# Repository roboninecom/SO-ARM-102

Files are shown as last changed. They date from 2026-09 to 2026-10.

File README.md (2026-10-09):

# SO-ARM 102

<div align="center">

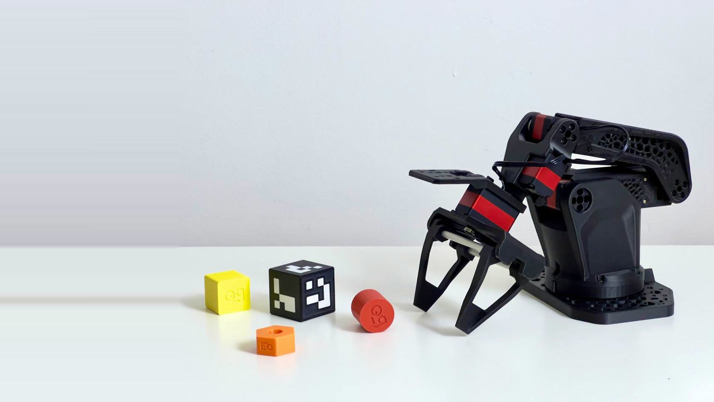
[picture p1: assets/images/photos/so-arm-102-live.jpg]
SO-ARM 102


**🎥 [Watch the preview video](assets/video/so-arm-102-preview.mp4)** · **🛒 [Buy the kit](https://robonine.com/shop/so-arm102-robotic-arm-kit/)**

**An open-source leader + follower robot arm kit with 5 degrees of freedom plus a gripper for teleoperation and imitation learning,
designed by [Robonine](https://robonine.com) as a stiffer, faster successor to the SO-ARM 101.**






📩 [hello@robonine.com](mailto:hello@robonine.com)

**DIY budget: ~$414 for components, or ~$469 including printing material.**
[BOM summary](#bill-of-materials) · [Itemised costs and purchase links](docs/bom.md#estimated-kit-cost)

> Rather not source the parts and print them yourself? **[Buy the SO-ARM 102 kit](https://robonine.com/shop/so-arm102-robotic-arm-kit/)**.

</div>

---

## ✨ What changed against SO-ARM 101

| | SO-ARM 101 | SO-ARM 102 |
|---|---|---|
| Gripper | Angular jaw | Parallel gripper, 85 mm span |
| Frame material | PLA | PET-CF (Fiberon PET-CF17 tested) |
| Structure | Solid links | Topology-optimised links |
| Base rotation range | 220° | **352°** |
| Horizontal reach | 441 mm | **483 mm** |
| Deflection at the gripper, 300 g load ¹ | 7.5 mm | **3.4–3.9 mm** |
| Shoulder and elbow speed | 45 RPM (STS3215) | **75 RPM (STS3250)** |
| Noise at 1 m | 70 dB | **60 dB** |

¹ Both arms built with printed servo dummies, so the frame is compared, not the motors.
Full results and test conditions are in [docs/specifications.md](docs/specifications.md).

The arm keeps the SO-ARM 101 joint layout, so it works with
[Hugging Face LeRobot](https://github.com/huggingface/lerobot) datasets and policies.

---

## 🎥 Preview

<div align="center">

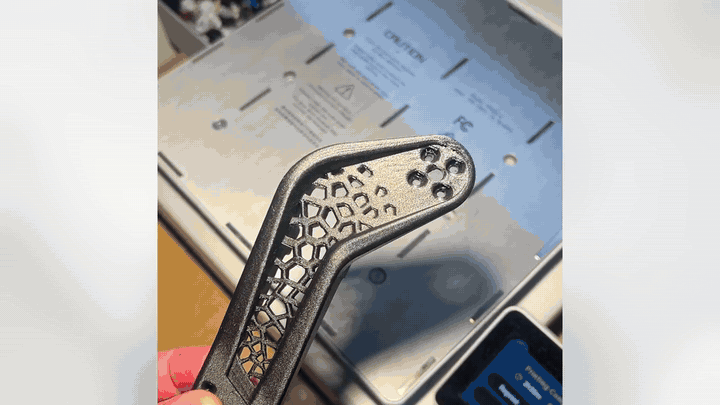
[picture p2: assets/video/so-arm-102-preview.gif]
SO-ARM 102 preview


*Click for the full video, 21 s*

</div>

---

## 🤝 Configurations

### Single-arm: one leader + one follower

The standard kit. Move the leader by hand, and the follower repeats the motion.
Use it for teleoperation and for recording demonstrations for imitation learning.

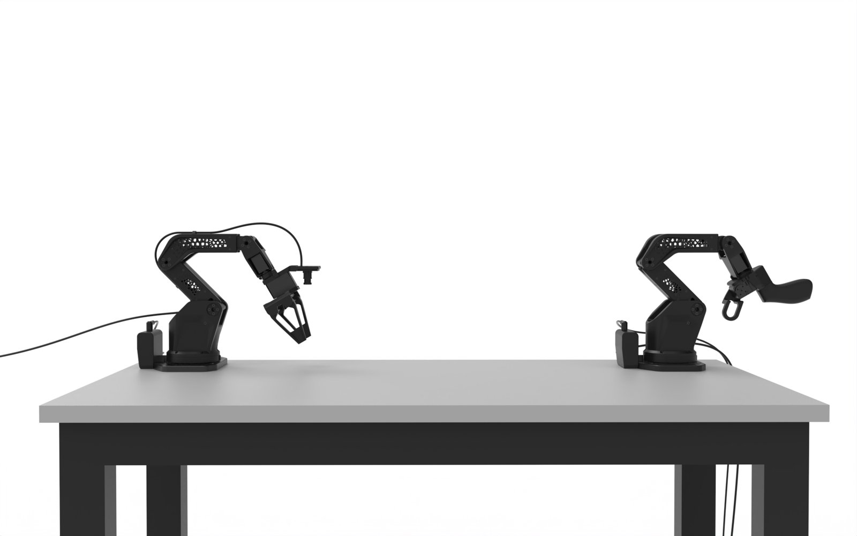
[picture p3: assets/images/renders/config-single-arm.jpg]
One leader and one follower


### Bimanual: two leaders + two followers

Two kits side by side. Each hand drives its own leader, so the followers can pass objects,
hold and work on a part, or do any task that needs two hands.

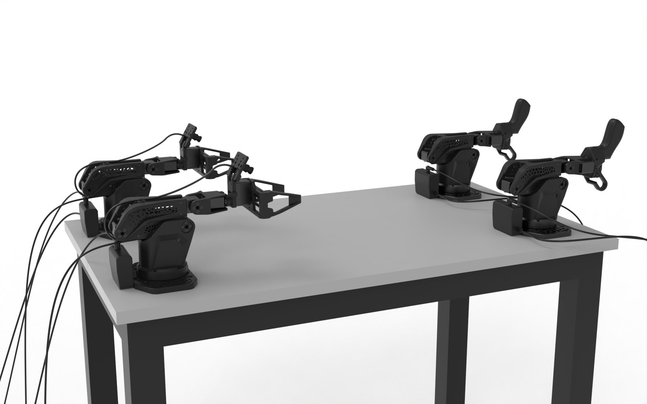
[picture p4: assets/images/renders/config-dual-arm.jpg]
Two leaders and two followers


### The two arms

| Follower | Leader |
|:-:|:-:|
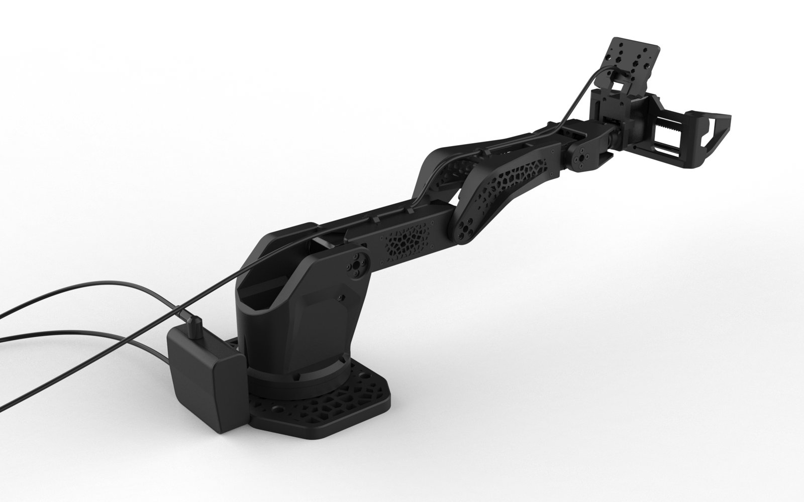
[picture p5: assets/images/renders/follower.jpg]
Follower arm
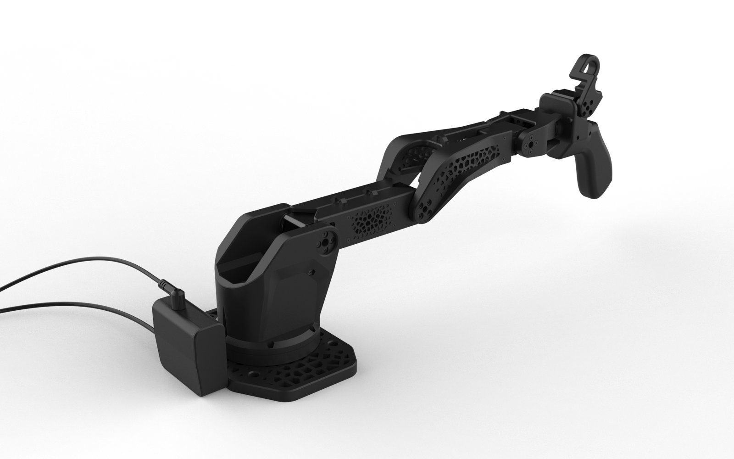
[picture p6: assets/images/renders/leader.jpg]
Leader arm
|  |  |
| Parallel gripper, wrist camera, 12 V | Handle with trigger, 5 V |

---

## 🚀 Build it in four steps

Prefer a ready kit? **[Buy the SO-ARM 102 kit](https://robonine.com/shop/so-arm102-robotic-arm-kit/)**.

### 1. Print the parts

Individual parts fit a 180 × 180 mm bed. The largest part is 160 mm long.
The supplied 3MF plate layouts use a 256 × 256 mm bed.

- 3MF slicer projects with saved orientation and support settings: [`models/3mf/`](models/3mf/)
  — [leader](models/3mf/SO102_leader.3mf), [follower arm](models/3mf/SO102_follower.3mf),
  [follower gripper and board case](models/3mf/SO102_follower_gripper_box.3mf)
- Project contents and printer profiles: [models/README.md](models/README.md)
- STL files, ready to slice: [`models/stl/`](models/stl/)
- STEP sources: [`models/step/`](models/step/)
- Material, settings and part quantities: [docs/printing.md](docs/printing.md)

The earlier test-arm settings gave slicer estimates of about 500 g of filament and 21 h
for the arm parts, excluding the gripper. Re-slice the 3MF projects for current estimates.

### 2. Buy the hardware

Source the components from the [BOM summary](#bill-of-materials) and
[full BOM with purchase links](docs/bom.md). Budget **$414.21** for components,
or **$469.19** including printing material, before shipping and taxes.

| Arm | Servos | Controller | Power |
|---|---|---|---|
| Follower | 2 × STS3235, 2 × STS3250, 2 × STS3215 | Waveshare Bus Servo Driver HAT | **12 V** |
| Leader | 6 × STS3215 | Waveshare Bus Servo Adapter | **5 V** |

> ⚠️ **The leader runs on 5 V and the follower on 12 V.** Do not swap the power supplies.

### 3. Assemble

- Printable booklet, 36 pages A5: [docs/SO-ARM102_assembly_A5_v0.6.pdf](docs/SO-ARM102_assembly_A5_v0.6.pdf)
- Step list with parts and fasteners: [docs/assembly-guide.md](docs/assembly-guide.md)

Tools: hex keys 1.5 mm (M2 screws) and 2 mm (M3 screws).

### 4. Set up the software

Servo IDs, calibration and lessons: **[lab.robonine.com](https://lab.robonine.com)**.
The arm uses the LeRobot SO-101 leader/follower workflow.

---

## Bill of materials

Quantities and reference costs for **one leader + one follower**:

| Category | Kit contents | Estimated cost (USD) |
|---|---|---:|
| Servos | 8 × STS3215, 2 × STS3235, 2 × STS3250 | $283.62 |
| Electronics | 2 controllers, 2 power supplies, 2 USB cables, 1 camera; servo cables included | $75.97 |
| Mechanical parts | 4 bearings, 2 steel guide rods, 4 table clamps | $40.76 |
| Fasteners | Screws and nuts; servo horn screws included with servos | $13.86 |
| **Components subtotal** | | **$414.21** |
| Printing material | 1 kg PET-CF17 + 0.25 kg PETG allowance | $54.98 |
| **Total with printing material** | | **$469.19** |

Buying the listed full packs and filament spools from scratch costs about **$545.17**,
including unused spares. Shipping, taxes, tools, a computer and a printer are excluded;
optional O-rings are extra. Confirm supplier prices, variants and minimum order quantities
before ordering. Re-slice the 3MF projects to check filament consumption.

[Full BOM, purchase links and cost assumptions](docs/bom.md#estimated-kit-cost).

---

## URDF export

The current standalone export is in [`simulation/urdf/`](simulation/urdf/):
[URDF](simulation/urdf/so_arm_102.urdf) · [Xacro](simulation/urdf/so_arm_102.xacro).
Keep `meshes/` beside the description files; mesh paths are relative to this folder.

- **Visuals:** STL meshes. **Collisions:** fitted, independently rotated boxes on all eight links.
- **Mass estimate:** PLA, 30% infill, 6 perimeters, 6 top/bottom layers,
  0.2 mm layer height, and **0.40 mm extrusion width**. These are simulation
  assumptions; use [the printing guide](docs/printing.md) for fabrication settings.
- **Hardware masses:** six motors at 70 g each; base bearing at 105 g.
  Total estimated model mass: **0.889 kg**.
- **Gripper:** `clamp2` mimics `clamp1` with multiplier `-1`.

[Export settings](simulation/urdf/export_settings.json) and
[mass properties](simulation/urdf/mass_properties.json) record the assumptions.
Geometry and inertia checks are recorded in

---

## 📁 Repository structure

```
├── models/
│   ├── 3mf/                 # Slicer projects: leader, follower, gripper and board case
│   ├── stl/                 # Print-ready meshes
│   │   ├── common/          #   parts used by both arms
│   │   ├── follower/        #   parallel gripper, camera mount, board case
│   │   └── leader/          #   handle, trigger, wrist roll, board case
│   └── step/                # CAD sources, same layout as stl/
├── docs/
│   ├── printing.md          # Material, slicer settings, quantities
│   ├── bom.md               # Bill of materials
│   ├── assembly-guide.md    # Step list with parts and fasteners
│   ├── specifications.md    # Geometry, servos, measured results vs SO-ARM 101
│   └── SO-ARM102_assembly_A5_v0.6.pdf
├── assets/
│   ├── images/              # Photos, renders, booklet pages, test photos
│   └── video/               # Preview video and GIF
├── LICENSING.md             # Which licence covers which file
└── NOTICE                   # Third-party attribution
```

---

## ⚠️ Known issues

This is the first public release. An independent test build found the following.
They are being fixed and will land in the next release.

1. **Two models are reported missing from the release set.** One is known: the camera holder still lacks a STEP source.
2. **M2 screws are hard to reach in several places.** Expect to fight a few of them.
3. **The gripper clamps run tight on carbon rods.** The clamp bores are sized for 6.1 mm. Rod diameters vary between suppliers, so check the fit before assembly.
4. **Check the servo cable lengths** before closing each joint, especially from the base to the shoulder.
5. **The assembly order is awkward in two places** of the booklet. Read two steps ahead before fastening.
6. **Leader joints can feel loose.** Adding 8 × 2 mm rubber O-rings between each servo and its horn gives the leader smooth, silent friction. Use two per servo on joints 1–4 and one on joints 5–6.

Found something else? Please [open an issue](https://github.com/roboninecom/SO-ARM-102/issues).

---

## 🔗 Related projects

- [SO-ARM100/101 Parallel Gripper](https://github.com/roboninecom/SO-ARM100-101-Parallel-Gripper), the gripper the SO-ARM 102 gripper grew from
- [SO-ARM101](https://github.com/TheRobotStudio/SO-ARM100) by TheRobotStudio, the arm this design succeeds
- [Practical comparison of smart serial servos](https://robonine.com/smart-serial-servo-motor-comparison-robotics/), the tests behind the servo choice
- [Choosing a filament for robotic arms](https://robonine.com/choosing-filament-for-robotic-arm-applications/), the tests behind PET-CF

---

## 📄 License

Copyright (c) 2026 Robonine. Different kinds of material carry different licences:

| Material | Licence |
|---|---|
| Hardware designs in `models/` | [CERN-OHL-P-2.0](HARDWARE-LICENSE.txt) |
| Software and configuration | [Apache-2.0](SOFTWARE-LICENSE.txt) |
| Documentation and images in `docs/`, `assets/`, all `README.md` | [CC BY 4.0](DOCS-LICENSE.txt) |

See [LICENSING.md](LICENSING.md) and [REUSE.toml](REUSE.toml) for the file-by-file map.

---

## 👥 Team

| Name | Role | Contact |
|---|---|---|
| **Alan Subin** | Design Engineer: mechanical design, CAD, assembly booklet | [LinkedIn](https://www.linkedin.com/in/alan-subin/) |
| **Boris Kotov** | Software and Test Engineer: prototypes, printing, test rigs | [Telegram](https://t.me/bkotov) |
| **Nikita Bragin** | Project Manager | [LinkedIn](https://www.linkedin.com/in/nikita-bragin-82296b29/) |
| **Mikhail Chistiakov** | Industrial Designer: look and form of the arm | [Telegram](https://t.me/brrryska) |
| **Mikhail Zhmaylo** | Structural Engineer: stiffness models, design changes to cut deflection | [Telegram](https://t.me/mikhail_zhmaylo) |
| **Vladislav Eremenko** | Structural Engineer: strength and thermal analysis, topology optimisation | [Telegram](https://t.me/v1ad_eremenko) |
| **Vladimir Osipov** | Tester and Consultant: independent test build | [LinkedIn](https://www.linkedin.com/in/vladimirosipov/) |

<div align="center">

**Built for the robotics community by [Robonine](https://robonine.com)** 🤖

</div>

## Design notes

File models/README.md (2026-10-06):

# 3D models

| Folder | Content |
|---|---|
| `3mf/` | Bambu Studio projects with saved plate layouts, orientation and support settings |
| `stl/` | Print-ready meshes, binary STL, millimetres |
| `step/` | CAD sources, one solid per file |

The `stl/` and `step/` folders use the same split:

- `common/` holds the parts both arms use. The quantities in the print table cover the whole kit.
- `follower/` holds the parallel gripper, the camera mount and the follower board case.
- `leader/` holds the handle, trigger, wrist roll and the leader board case.

## 3MF slicer projects

| Project | Contents | Saved filament profile |
|---|---|---|
| [SO102_leader.3mf](3mf/SO102_leader.3mf) | One leader: arm parts, handle, trigger, wrist roll and board case | Bambu PETG-CF |
| [SO102_follower.3mf](3mf/SO102_follower.3mf) | One follower's arm parts | Fiberon PET-CF17 |
| [SO102_follower_gripper_box.3mf](3mf/SO102_follower_gripper_box.3mf) | Follower gripper, camera holder and spacer, and board case | Bambu PETG-CF |

Open these files as projects in **Bambu Studio** to retain the saved settings.
All three use the **Bambu Lab A1, 0.4 mm nozzle** profile and one **256 × 256 mm** plate each.
Select your printer, nozzle and filament before slicing. For a smaller bed, split the parts
across additional plates while preserving their orientations and support settings.

For one leader + one follower, print all three projects once. The arm projects each include
the common parts for one arm; there is no need to print a separate common set.

Saved settings and layout previews are in [docs/printing.md](../docs/printing.md#3mf-slicer-projects).

Part numbers, quantities and print settings are in [docs/printing.md](../docs/printing.md).

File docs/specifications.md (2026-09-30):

# Specifications and test results

Measured on Robonine prototypes in August and September 2026.
Numbers marked *calculated* come from the URDF model and servo datasheets, not from a measurement.

## Geometry

| Joint | Range |
|---|---|
| Base rotation | −176° … +176° (352°) |
| Shoulder lift | −43° … +181° (224°) |
| Elbow flex | −166° … +77° (243°) |
| Wrist flex | −85° … +111° (196°) |
| Wrist roll | −165° … +163° (328°) |
| Gripper | 0 … 85 mm |

| Link | Axis to axis |
|---|---|
| Base rotation to shoulder | 85 mm |
| Shoulder to elbow | 119 mm |
| Elbow to wrist flex | 139 mm |
| Wrist flex to wrist roll | 62 mm |
| Wrist roll to gripper tip | 132 mm |

| Reach, gripper tip centre | |
|---|---|
| Horizontal radius | 483 mm |
| Height above the base bottom | up to 544 mm |
| Below the base bottom, arm over a table edge | down to −301 mm |

Reach was computed from 100,000 random poses within the joint limits, with no self-collisions.

## Servos

| Joint | Follower | Leader |
|---|---|---|
| 1 Base rotation | STS3235 | STS3215 |
| 2 Shoulder lift | STS3250 | STS3215 |
| 3 Elbow flex | STS3250 | STS3215 |
| 4 Wrist flex | STS3235 | STS3215 |
| 5 Wrist roll | STS3215 1:345 | STS3215 |
| 6 Gripper / trigger | STS3215 | STS3215 |
| Supply | 12 V | 5 V |

## Gripper

| | |
|---|---|
| Type | Parallel, rack and pinion, two moving jaws |
| Span | 85 mm |
| Box, recommended maximum width | about 75 mm |
| Cylinder, recommended maximum diameter | about 70 mm |
| Sphere, recommended maximum diameter | about 60 mm |
| Camera | USB camera mounted on the gripper |

## Measured results against SO-ARM 101

| Metric | SO-ARM 101 | SO-ARM 102 | Change |
|---|---|---|---|
| Deflection at the gripper tip, 300 g, arm fully extended ¹ | 7.5 mm | 3.4 mm | −55 % |
| Same, all links at 100 % infill ¹ | — | 2.34 mm | −69 % |
| Horizontal radius | 441 mm | 483 mm | +9.5 % |
| Reach behind the base | 377 mm | 473 mm | +25.5 % |
| Base rotation range | 220° | 352° | +60 % |
| Elbow range | 194° | 243° | +25 % |
| Shoulder and elbow no-load speed, *calculated* | 270 °/s | 450 °/s | +67 % |
| Base joint backlash | 8.75 counts | 5.00 counts | −43 % |
| Horizontal tip error from base backlash, *calculated* | ±2.96 mm | ±1.85 mm | −37.5 % |
| Repeatability | — | about 0.1 mm | |
| Noise at 1 m | 70 dB | 60 dB | −10 dB |
| Rated payload | 250 g | 300 g | |

¹ Both arms were built with printed servo dummies in joints 2, 3 and 4, so only the frame is compared.
SO-ARM 101 printed in PLA, SO-ARM 102 in Fiberon PET-CF17 at 25 % infill.
A second run of the same SO-ARM 102 test gave 3.9 mm.

| SO-ARM 101 | SO-ARM 102 |
|:-:|:-:|
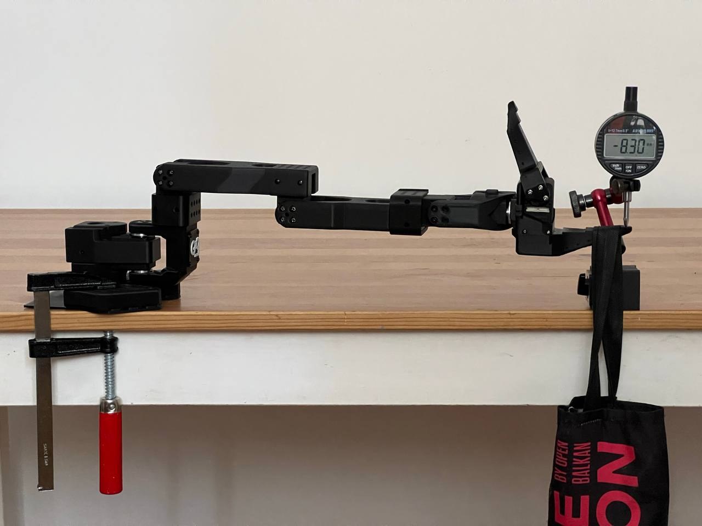
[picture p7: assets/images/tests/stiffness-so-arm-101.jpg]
SO-ARM 101 stiffness test
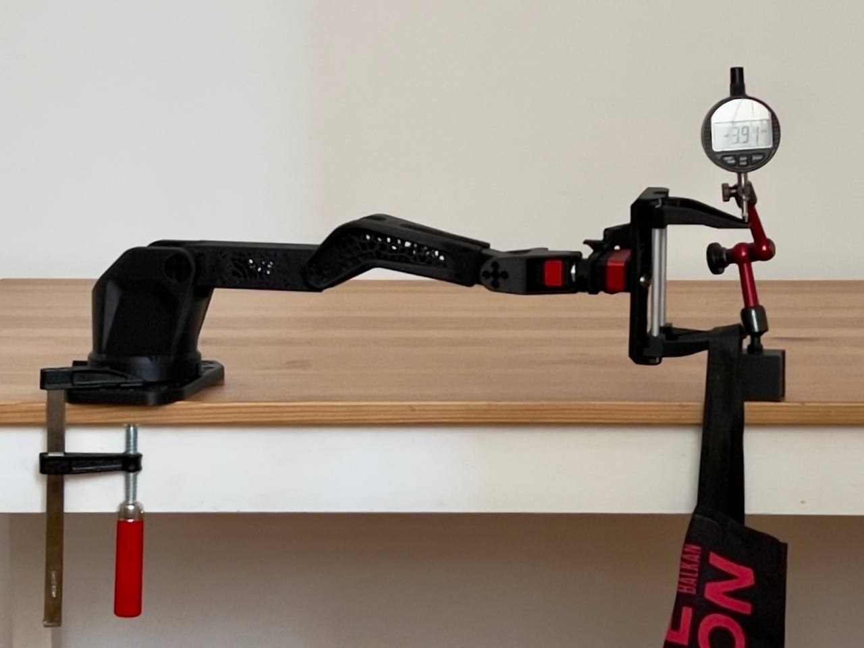
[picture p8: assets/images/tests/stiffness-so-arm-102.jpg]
SO-ARM 102 stiffness test
|  |  |

## Current and temperature, follower

Measured with a 300 g load on a repeating trajectory, ambient 30 °C, six STS3250 servos.

| | |
|---|---|
| Current, average | 1.26 A |
| Current, peak | 3.28 A |
| Servo temperature, maximum | 46 °C |

## Absolute accuracy

Still being tuned. With stock servo PID settings the tip sagged about 50 mm under the arm's own weight at full extension.
Tuned PID settings brought that down to about 5 mm. A dedicated accuracy profile is in progress.

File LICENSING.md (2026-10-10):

# Licensing

Copyright (c) 2026 Robonine

This project releases different kinds of material under different licences.
Every file in this repository is covered by exactly one of them.

| Material | Licence | Text |
|---|---|---|
| Hardware designs (CAD, manufacturable geometry) | CERN-OHL-P-2.0 | [`HARDWARE-LICENSE.txt`](HARDWARE-LICENSE.txt) |
| Software (configuration, CI) | Apache-2.0 | [`SOFTWARE-LICENSE.txt`](SOFTWARE-LICENSE.txt) |
| Documentation, renders, photographs and simulation assets | CC-BY-4.0 | [`DOCS-LICENSE.txt`](DOCS-LICENSE.txt) |

The machine-readable version of this map is [`REUSE.toml`](REUSE.toml).
`LICENSES/` holds the same three texts under their SPDX names, as the REUSE Specification requires.
The copies at the root are the ones GitHub's licence detection reads.

## 1. Hardware: CERN-OHL-P-2.0

```
models/step/    *.STEP
models/stl/     *.stl
models/3mf/     *.3mf (geometry and slicer projects)
```

`models/README.md` is documentation and falls under CC-BY-4.0.

Recommended notice when reusing this hardware:

```
Copyright (c) 2026 Robonine

This source describes Open Hardware and is licensed under the CERN-OHL-P v2.
You may redistribute and modify this source and make products using it under
the terms of the CERN-OHL-P v2 (https://ohwr.org/cern_ohl_p_v2.txt).

This source is distributed WITHOUT ANY EXPRESS OR IMPLIED WARRANTY, INCLUDING
OF MERCHANTABILITY, SATISFACTORY QUALITY AND FITNESS FOR A PARTICULAR PURPOSE.

SPDX-License-Identifier: CERN-OHL-P-2.0
```

## 2. Software: Apache-2.0

```
.github/    .pre-commit-config.yaml    .gitignore    .gitattributes
```

## 3. Documentation and simulation assets: CC-BY-4.0

```
README.md, CONTRIBUTING.md, LICENSING.md, CLAUDE.md, NOTICE
docs/             *.md, *.pdf
assets/images/    *.jpg
assets/video/     *.mp4, *.gif
simulation/       all files, including URDF/Xacro descriptions, meshes and export metadata
every other README.md in the repository
```

All files under `simulation/` are licensed under CC-BY-4.0. This includes the
robot descriptions in `simulation/urdf/` and their referenced STL meshes in
`simulation/urdf/meshes/`. The fabrication designs under `models/` remain
licensed under CERN-OHL-P-2.0 as described above.

Attribution for reuse: "Robonine, SO-ARM 102, https://github.com/roboninecom/SO-ARM-102, CC BY 4.0".

## 4. Third-party material

No file in this repository is copied from a third party.
See [`NOTICE`](NOTICE) for the projects this design builds on.

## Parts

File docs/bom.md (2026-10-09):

# Bill of materials

Quantities are for one complete kit: one follower arm and one leader arm.
Printed parts are listed separately in [printing.md](printing.md).

## Estimated kit cost

**One leader + one follower: $414.21 in components, or $469.19 including printing material.**

| Category | Cost of quantities used (USD) | Buy full packs / spools (USD) |
|---|---:|---:|
| Servos (12) | $283.62 | $283.62 |
| Electronics, camera, power supplies and USB cables | $75.97 | $75.97 |
| Bearings, steel guide rods and table clamps | $40.76 | $55.88 |
| Fasteners (servo horn screws included with servos) | $13.86 | $59.72 |
| **Components subtotal** | **$414.21** | **$475.19** |
| Printing material: 1 kg PET-CF17 + 0.25 kg PETG | $54.98 | $69.98 |
| **Total with printing material** | **$469.19** | **$545.17** |

Estimates use the reference prices listed below, with each line rounded to cents.
They are not new supplier quotes: confirm the selected variants, minimum order
quantities and prices before ordering. Shipping, taxes, tools, a computer, a printer,
electricity and assembly labour are excluded. Optional O-rings add $0.72 in parts
used, or $6.00 for a pack of 100; tools add about $10.00 if needed.

The full-pack column includes unused spares, two 0.5 kg PET-CF17 spools and one
1 kg PETG spool. Printing quantities are budget allowances; re-slice the supplied
3MF projects for your settings. Rod costs use steel; carbon tubes are an alternative.

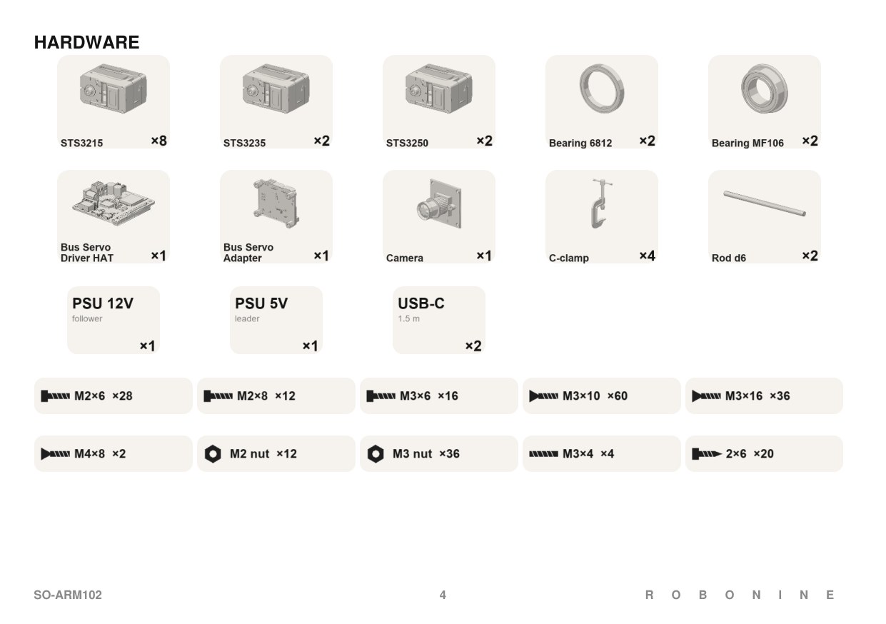
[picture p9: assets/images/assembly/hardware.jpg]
Kit hardware


## Servos

| Joint | ID | Follower | Leader |
|---|:-:|---|---|
| Base rotation | 1 | ST-3235-С001 | ST-3215-C044, 1:191 |
| Shoulder lift | 2 | ST-3250-С002 | ST-3215-C044, 1:191 |
| Elbow flex | 3 | ST-3250-С002 | ST-3215-C044, 1:191 |
| Wrist flex | 4 | ST-3235-С001 | ST-3215-C044, 1:191 |
| Wrist roll | 5 | ST-3215-C049, 1:191 | ST-3215-C044, 1:191 |
| Gripper / Trigger | 6 | ST-3215-C049, 1:191 | ST-3215-C044, 1:191 |

Totals: 6 × STS3215 7.4V, 2 × STS3215 12V, 2 × STS3235 12V, 2 × STS3250 12V. All are Feetech TTL serial bus servos.

| Servo | Qty | Purchase link | Selection | Unit price (USD) | Kit cost (USD) |
|---|---|---|---|---|---|
| STS3215 | 6 | [Alibaba](https://www.alibaba.com/product-detail/Top-Seller-Low-Cost-Feetech-STS3215_1600999461525.html) | 7.4V TTL version for leader servos. Select ST-3215-C044 (7.4V). | $13.89 | $83.34 |
| STS3215 | 2 | [Alibaba](https://www.alibaba.com/product-detail/6pcs-12V-30KG-1-345-STS3215_1601900233170.html) | 12V TTL version for follower joints 5 and 6. Select ST-3215-C049 (12V30KG). | $14.70 | $29.40 |
| STS3235 | 2 | [Alibaba](https://www.alibaba.com/product-detail/FEETECH-STS3235-12V-30KG-TTL-Dual_1601910640629.html) | 12V TTL version for follower joints 1 and 4. | $40.79 | $81.58 |
| STS3250 | 2 | [Alibaba](https://www.alibaba.com/product-detail/Feetech-STS3250-12V-50kg-Servo-High_1601711893549.html) | 12V TTL version for follower joints 2 and 3. | $44.65 | $89.30 |

- **Follower, 12V.** STS3250 is a 50 kg·cm brushless servo at 75 RPM. It drives the two joints that carry the most load.
  STS3235 is a 30 kg·cm servo with lower backlash than the STS3215.
- **Leader, 5V.** The leader servos are only read, never loaded. You can use a passive STS3215 (ST-3215-C066) without motor and gearbox **only** for leader arm.
- Servo horns and the M3 × 6 horn screws come with the servos.

## Electronics

| Item | Qty | Notes | Purchase link | Unit / pack price (USD) | Kit cost (USD) |
|---|---|---|---|---|---|
| Waveshare Bus Servo Driver HAT | 1 | Follower controller | [Waveshare HAT (A)](https://www.waveshare.com/product/robotics/bus-servo-driver-hat-a.htm) | $18.99 | $18.99 |
| Waveshare Bus Servo Adapter | 1 | Leader controller | [Waveshare Adapter (A)](https://www.waveshare.com/bus-servo-adapter-a.htm) | $4.99 | $4.99 |
| Power supply 12V DC | 1 | Follower. 60W / 5A or more recommended. The arm peaked at 3.3A under a 300g load. Match the HAT's connector (5.5x2.5mm). | [Amazon search](https://www.amazon.com/s?k=12V+5A+power+supply+5.5+2.5mm) | ~$20.00 | $20.00 |
| Power supply 5V DC | 1 | Leader. Match the Adapter's connector (5.5x2.1mm). | [Amazon search](https://www.amazon.com/s?k=5V+power+supply+5.5+2.1mm) | ~$10.00 | $10.00 |
| USB-C cable, 1.5 m | 2 | One per controller. Choose a data cable, not a charging-only cable. | [Amazon search](https://www.amazon.com/s?k=USB+A+to+USB+C+data+cable+1.5m) | ~$7.00 / 2 | $7.00 |
| USB camera, 1080p | 1 | Wrist camera on the follower gripper. The prototype used an OV2735 module. Check module dimensions and mounting holes against the camera holder. | [Waveshare OV2735](https://www.waveshare.com/ov2735-2mp-usb-camera-a.htm) | $14.99 | $14.99 |
| Servo cables | 12 | Come with the servos. Pay attention during assembly where to put 4 long cables from STS3250 packing. | Included with the [servos](#servos); [Amazon search for spares](https://www.amazon.com/s?k=Feetech+STS3215+TTL+servo+cable) | Included | $0.00 |

## Mechanical parts

| Item | Size | Qty | Where | Purchase link | Unit / pack price (USD) | Kit cost (USD) |
|---|---|---|---|---|---|---|
| Ball bearing 6812 | 60 × 78 × 10 mm | 2 | Base rotation, one per arm | [Amazon search](https://www.amazon.com/s?k=6812+bearing+60+78+10mm) | ~$7.00 | $14.00 |
| Flanged bearing MF106ZZ | 6 × 10 × 3 mm | 2 | Gripper main frame | [Amazon](https://www.amazon.com/uxcell-MF106ZZ-6x10x3mm-Shielded-Bearings/dp/B08H289LLQ) | $9.99 / 10 | $2.00 |
| Rod | Ø6 × 125 mm, carbon or steel | 2 | Gripper guides | [Amazon steel rods](https://www.amazon.com/SKYPRO-Stainless-Diameter-Industry-Working/dp/B0CLCSWSJ9) · [Amazon carbon tubes](https://www.amazon.com/MECCANIXITY-Carbon-Pultruded-Airplane-Quadcopter/dp/B0CZDCW2NL) (cut to 125 mm) | $11.89 / 5 steel rods | $4.76 |
| C-clamp | 3 inch, 0–75 mm opening | 4 | Two per arm, to fix the base to the table | [Amazon search](https://www.amazon.com/s?k=3+inch+C+clamp+75mm) | ~$5.00 | $20.00 |
| Rubber O-ring, optional | 8 × 2 mm | 12 | Adds friction to the leader joints. Two per servo on joints 1–4, one on joints 5–6. | [Amazon search](https://www.amazon.com/s?k=rubber+O+ring+8mm+inner+diameter+2mm+cross+section) | ~$6.00 / 100 | $0.72 (optional) |

## Fasteners

Kit totals as packed in the assembly booklet.

| Fastener | Standard | Qty | Purchase link | Unit / pack price (USD) | Kit cost (USD) |
|---|---|---|---|---|---|
| M2 × 6 socket head | DIN 912 | 28 | [Amazon search](https://www.amazon.com/s?k=DIN+912+M2x6+socket+head+screw) | ~$6.99 / 100 | $1.96 |
| M2 × 8 socket head | DIN 912 | 12 | [Amazon](https://www.amazon.com/TOP-VIGOR-Stainless-Replacement-Motorcycle-Repairment/dp/B0D5CHC6GR) | $6.79 / 120 | $0.68 |
| M3 × 6 Phillips-head screw | from servo kit | 16 | Included with the [servos](#servos). | Included | $0.00 |
| M3 × 10 countersunk | DIN 7991 | 60 | [Amazon search](https://www.amazon.com/s?k=DIN+7991+M3x10+countersunk+screw) | ~$6.99 / 100 | $4.20 |
| M3 × 16 countersunk | DIN 7991 | 36 | [Amazon search](https://www.amazon.com/s?k=DIN+7991+M3x16+countersunk+screw) | ~$6.99 / 100 | $2.52 |
| M4 × 8 countersunk | DIN 7991 | 2 | [Amazon](https://www.amazon.com/Socket-Countersunk-Stainless-Screwdriver-Included/dp/B0DWZVYSMZ) | $6.99 / 100 | $0.14 |
| M3 × 4 set screw | DIN 913 | 4 | [Amazon](https://www.amazon.com/Socket-M3-0-5-Metric-14-9-45H-Quantity/dp/B07CPNB1WP) | $6.99 / 100 | $0.28 |
| M2 hex nut | DIN 934 | 12 | [Amazon](https://www.amazon.com/QXSKSLH-Metric-Stainless-Hex-Nuts-100pcs/dp/B0CSWRN19Q) | $5.99 / 100 | $0.72 |
| M3 hex nut | DIN 934 | 36 | [Amazon search](https://www.amazon.com/s?k=DIN+934+M3+hex+nut) | ~$5.99 / 100 | $2.16 |
| Self-tapping screw 2 × 6 | — | 20 | [Amazon search](https://www.amazon.com/s?k=2mm+x+6mm+self+tapping+screw) | ~$6.00 / 100 | $1.20 |

Black fasteners match the look of the renders but are not required.

## Printing materials

| Material | Use | Purchase link | Price / budget (USD) |
|---|---|---|---|
| Fiberon PET-CF17 | Tested material for the arm links, bases and servo holders | [Polymaker](https://shop.polymaker.com/products/fiberon-pet-cf17) | $24.99 / 0.5 kg; budget 2 spools = $49.98 |
| PETG or PET-CF | Gripper clamps, covers, leader handle and trigger | [Amazon PETG search](https://www.amazon.com/s?k=PETG+filament+1.75mm) · [Polymaker PET-CF17](https://shop.polymaker.com/products/fiberon-pet-cf17) | PETG: ~$20.00 / kg; 0.25 kg allowance = $5.00 |

Use the [printing guide](printing.md) and re-slice the supplied 3MF projects to determine
the filament quantity for your printer and settings.

## Tools

Allow about **$10.00** for a small hex-key and screwdriver set if you do not already own these tools.

- Hex key 1.5 mm for M2 screws: [Amazon search](https://www.amazon.com/s?k=1.5mm+hex+key)
- Hex key 2 mm for M3 screws: [Amazon search](https://www.amazon.com/s?k=2mm+hex+key)
- Phillips PH1 screwdriver for servo horn screws: [Amazon search](https://www.amazon.com/s?k=PH1+Phillips+screwdriver)

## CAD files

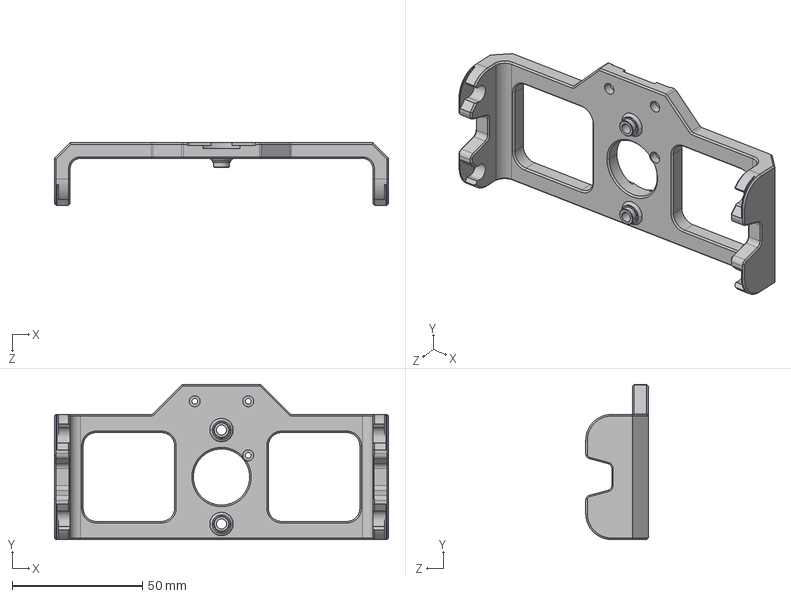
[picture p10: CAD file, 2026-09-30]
models/step/follower/RB9.01.062.011 Main frame (D6.1).STEP
128.0 x 59.5 x 24.0 mm

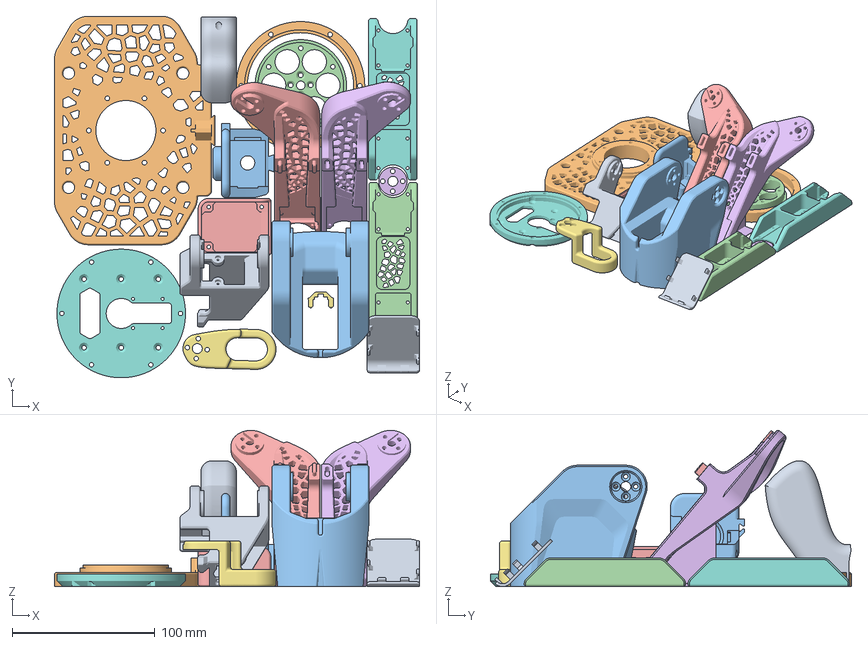
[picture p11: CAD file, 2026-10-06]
models/3mf/SO102_leader.3mf
255.6 x 253.1 x 109.4 mm
Handle_SO102
SO102.01.010 Base
Wrist_Roll_SO102
SO102.02.020 Base ring
SO102.02.110 Board holder leader
SO102.02.030 Base washer
Trigger_SO102
SO102.02.040 Bottom top plate
SO102.02.110-01 Board cap leader
SO102.02.050 Bottom ring
SO102.02.060 Bottom servo holder
SO102.02.070 Bottom arm x 2
SO102.02.080 Upper arm left
SO102.02.080-01 Upper arm right
SO102.02.130 Cable snap
SO102.02.090 Wrist holder

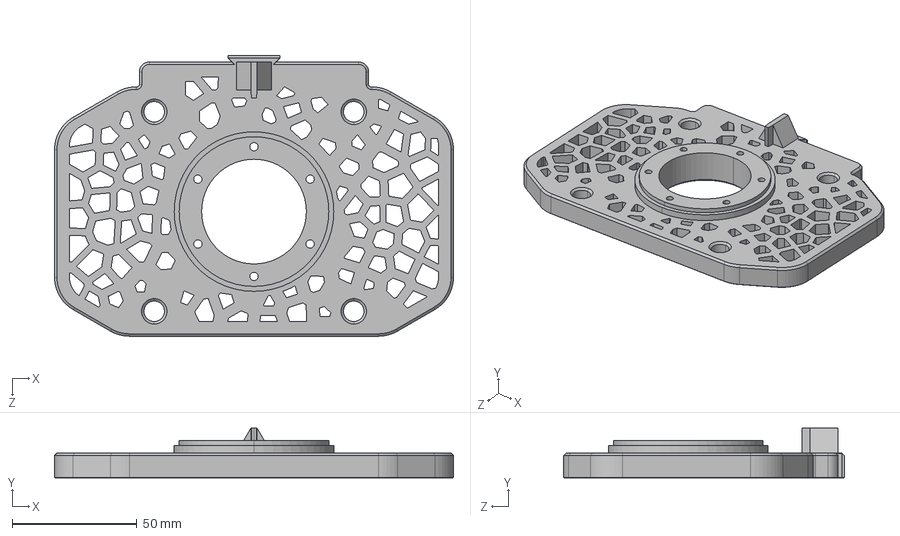
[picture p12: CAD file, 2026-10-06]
models/step/common/SO102.02.010 Base.STEP
160.0 x 20.0 x 112.5 mm

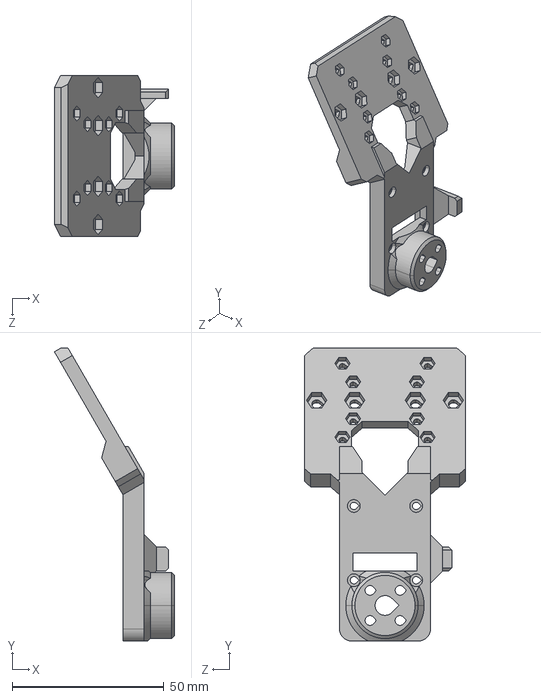
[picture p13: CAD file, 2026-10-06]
models/step/follower/RB9.01.062.075 Camera holder.STEP
39.6 x 96.5 x 53.0 mm

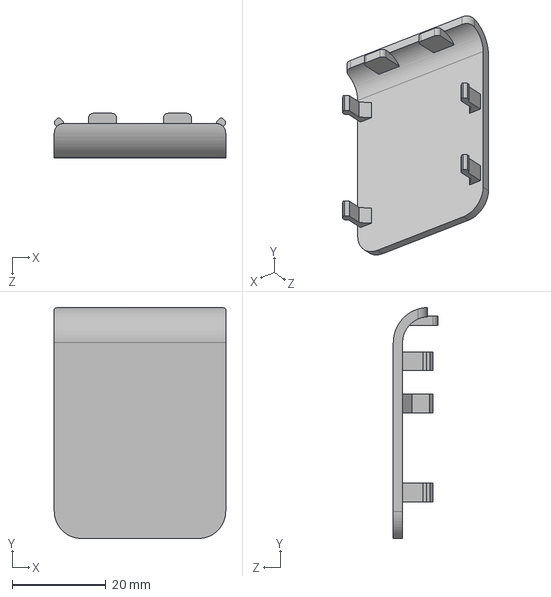
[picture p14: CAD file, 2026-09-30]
models/step/leader/SO102.02.110-01 Board cap leader.STEP
36.6 x 49.3 x 9.50 mm

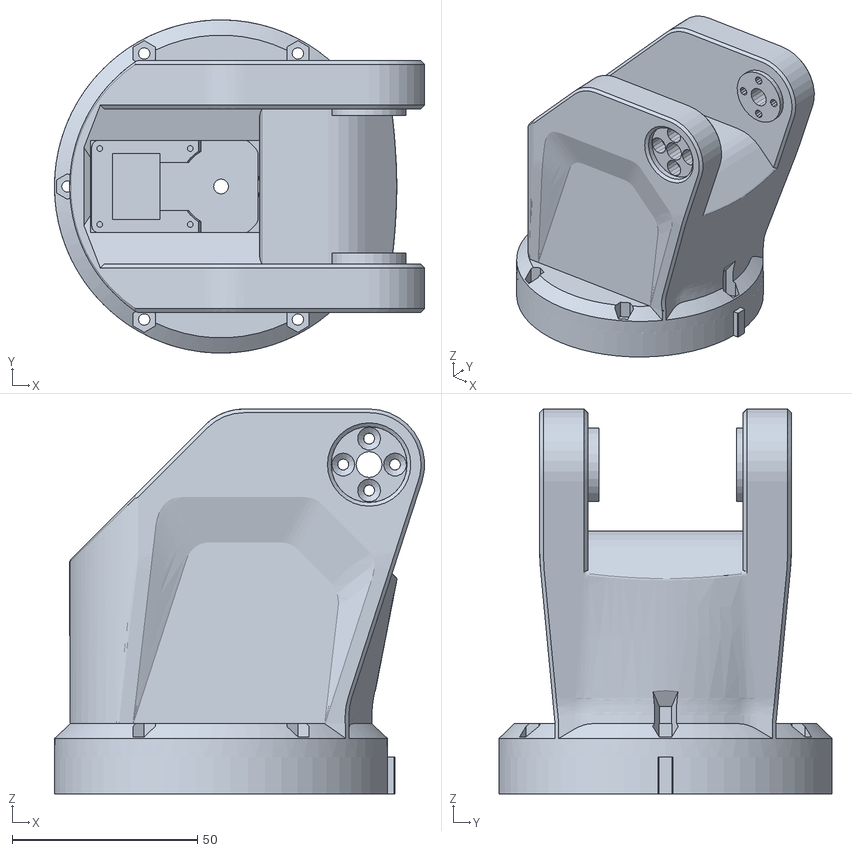
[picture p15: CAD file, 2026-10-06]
simulation/urdf/meshes/link1_1.stl
100.0 x 90.0 x 104.0

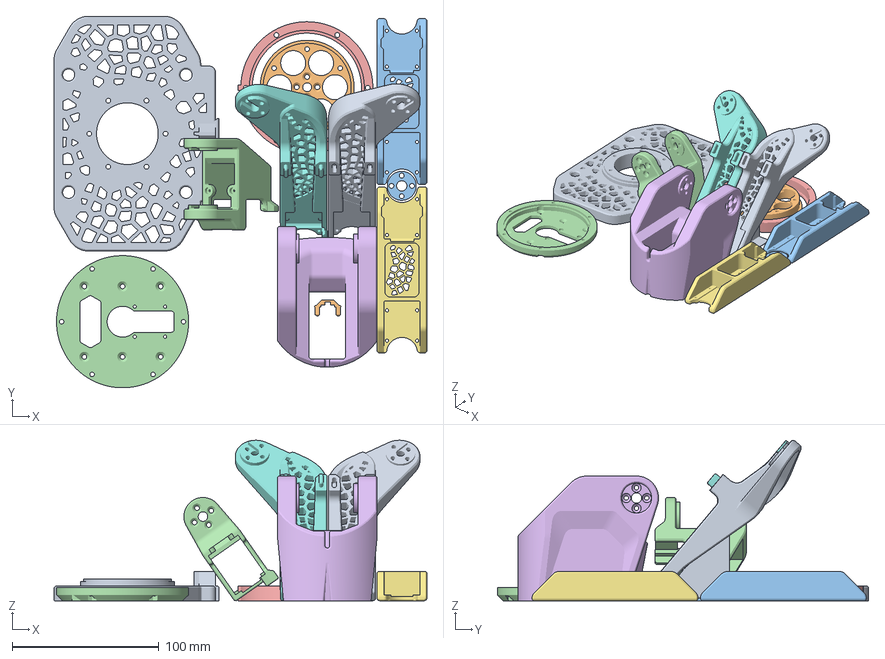
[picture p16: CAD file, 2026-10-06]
models/3mf/SO102_follower.3mf
254.1 x 253.1 x 109.4 mm
SO102.01.010 Base
SO102.02.020 Base ring
SO102.02.030 Base washer
SO102.02.040 Bottom top plate
SO102.02.050 Bottom ring
SO102.02.060 Bottom servo holder
SO102.02.070 Bottom arm x 2
SO102.02.080 Upper arm left
SO102.02.080-01 Upper arm right
SO102.02.130 Cable snap
SO102.02.090 Wrist holder

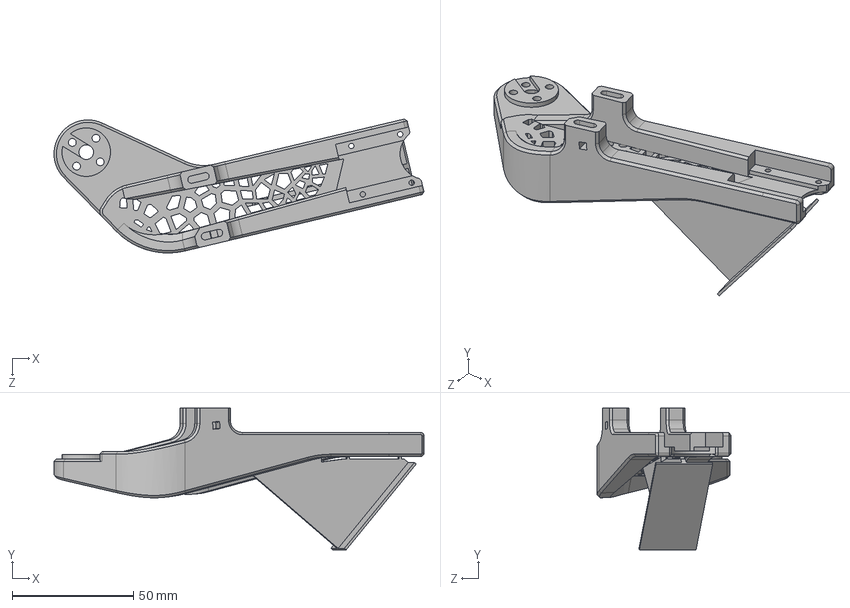
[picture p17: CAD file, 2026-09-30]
models/step/common/SO102.02.080-01 Upper arm right.STEP
152.6 x 58.5 x 55.2 mm

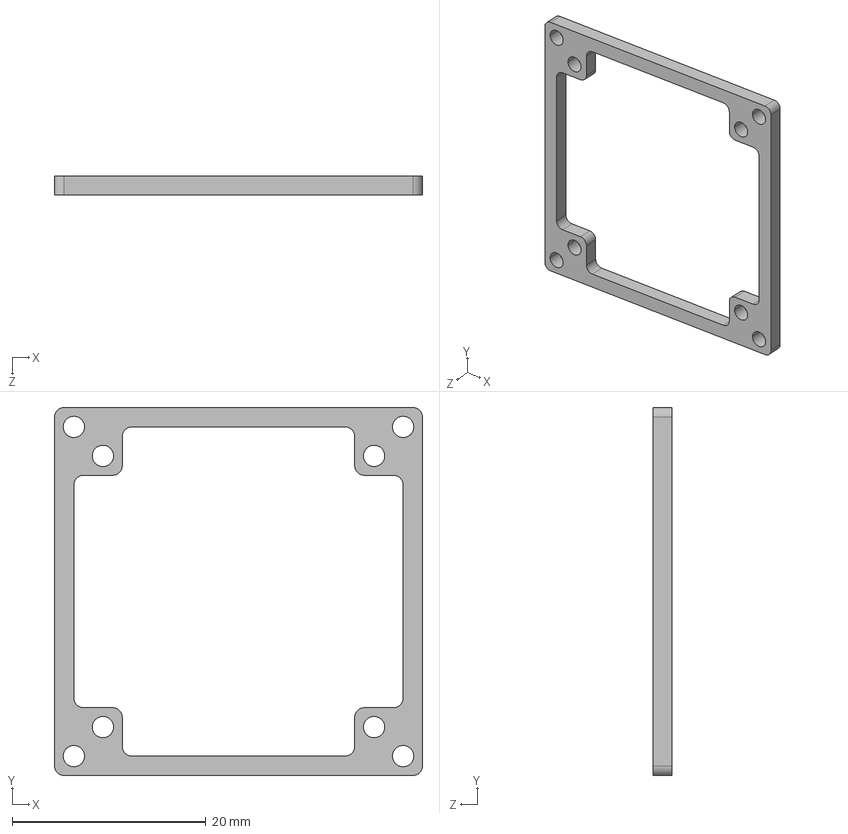
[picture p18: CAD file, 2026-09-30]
models/step/follower/RB9.01.062.090 Camera spacer.STEP
38.0 x 38.0 x 2.00 mm

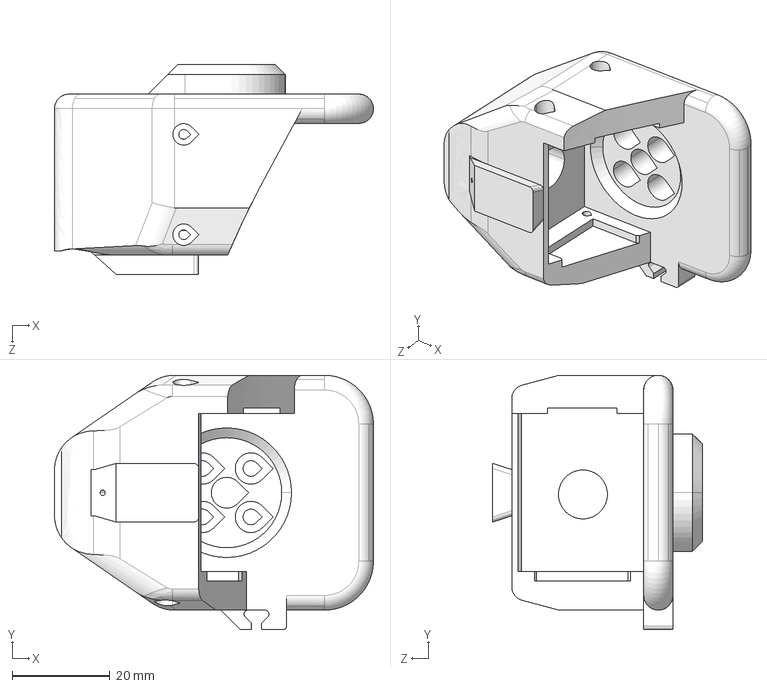
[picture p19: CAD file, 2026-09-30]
models/step/leader/SO102 Wrist roll.STEP
65.2 x 52.0 x 42.9 mm

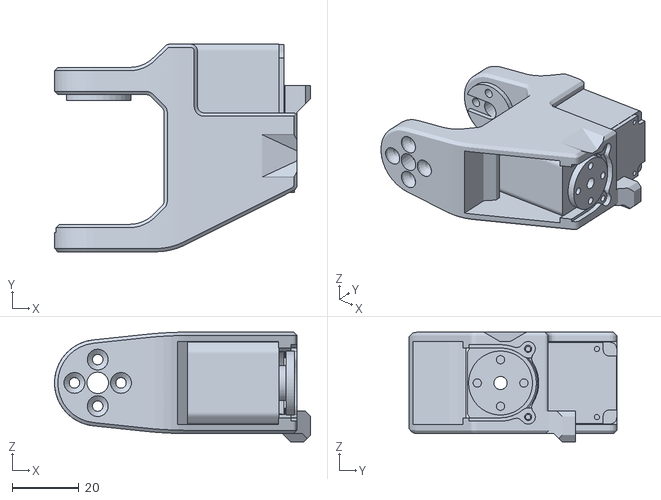
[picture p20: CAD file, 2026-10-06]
simulation/urdf/meshes/link4_1.stl
77.0 x 62.5 x 33.0

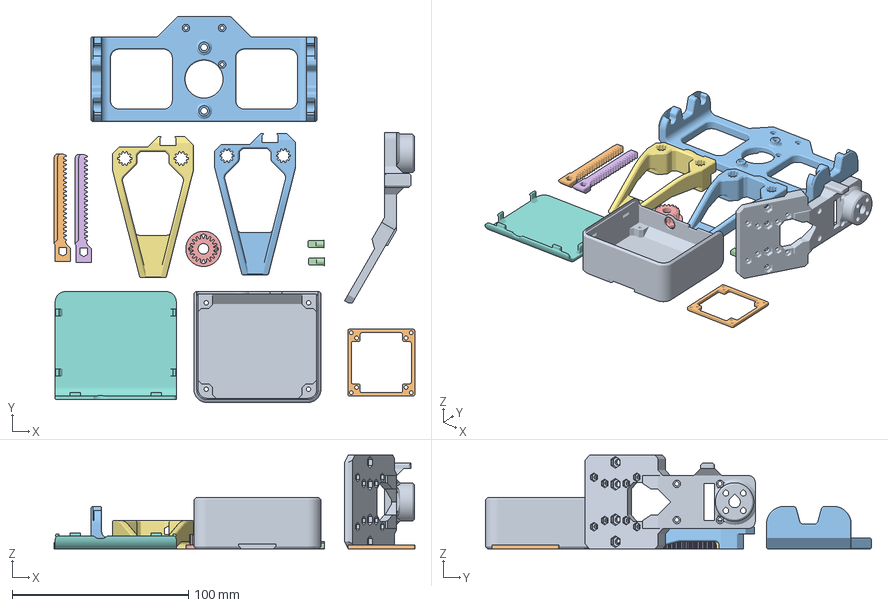
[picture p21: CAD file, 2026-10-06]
models/3mf/SO102_follower_gripper_box.3mf
204.4 x 218.7 x 53.0 mm
RB9.01.062.075 Camera holder
RB9.01.062.090 Camera spacer
RB9.01.062.011 Main frame (D6.1)
RB9.01.062.100 Nail x 2
RB9.01.062.040 Gear for gripper
RB9.01.062.030 Gear rack x 2
RB9.01.062.024 (D6.1) Clamp x 2
SO102.02.100-01 Board cap follower
SO102.02.100 Board holder follower

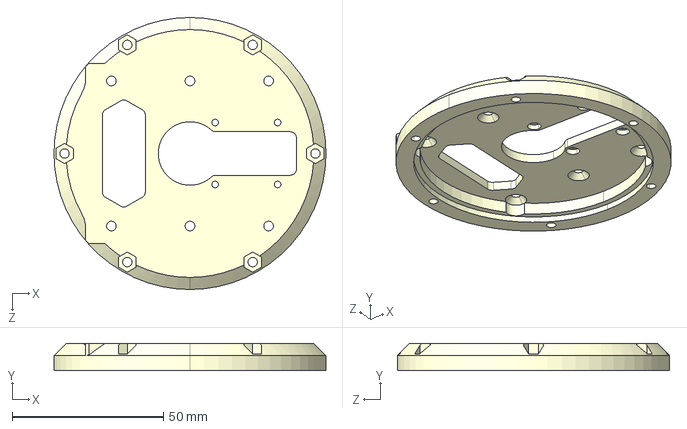
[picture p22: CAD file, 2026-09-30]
models/step/common/SO102.02.040 Bottom top plate.STEP
90.0 x 9.00 x 90.0 mm

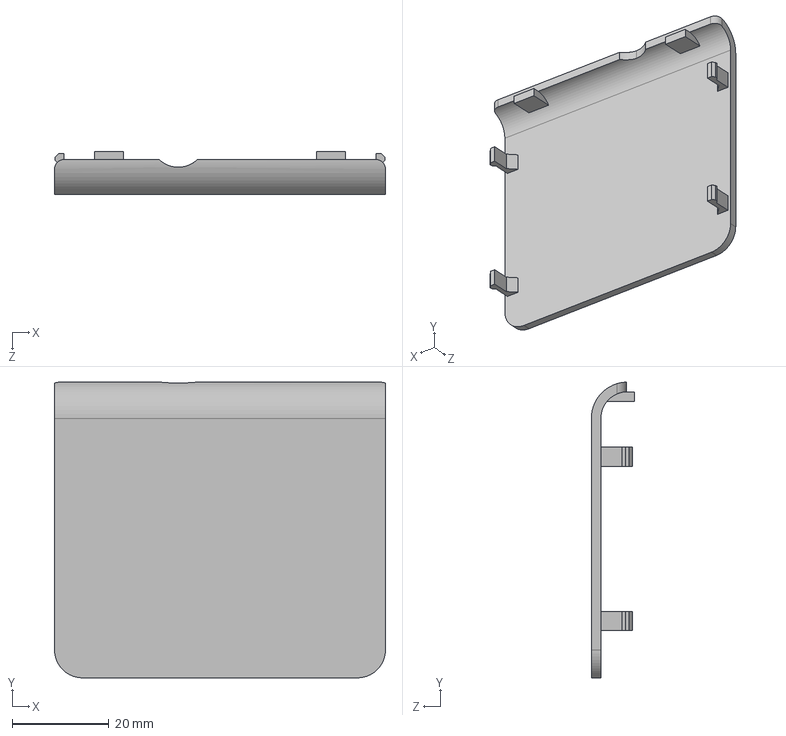
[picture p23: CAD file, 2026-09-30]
models/step/follower/SO102.02.100-01 Board cap follower.STEP
68.6 x 61.3 x 9.00 mm

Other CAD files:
models/step/leader/SO102 Trigger.STEP
simulation/urdf/meshes/link2_1.stl
models/step/common/SO102.02.070 Bottom arm.STEP
models/step/follower/RB9.01.062.040 Gear for gripper.STEP
models/step/common/SO102.02.020 Base ring.STEP
models/step/common/SO102.02.030 Base washer.STEP
models/step/common/SO102.02.050 Bottom ring.STEP
models/step/common/SO102.02.060 Bottom servo holder.STEP
models/step/common/SO102.02.080 Upper arm left.STEP
models/step/common/SO102.02.090 Wrist holder.STEP
models/step/common/SO102.02.130 Cable snap.STEP
models/step/follower/RB9.01.062.024 (D6.1) Clamp.STEP
models/step/follower/RB9.01.062.030 Gear rack.STEP
models/step/follower/RB9.01.062.100 Nail.STEP
models/step/follower/SO102.02.100 Board holder follower.STEP
models/step/leader/SO102 Handle.STEP
models/step/leader/SO102.02.110 Board holder leader.STEP
models/stl/common/SO102.02.010 Base.stl
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

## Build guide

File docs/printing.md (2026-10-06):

# Printing the parts

Every printed part of the SO-ARM 102 kit is in [`../models/stl/`](../models/stl/).
The editable CAD sources with the same names are in [`../models/step/`](../models/step/).

- `common/` holds the parts both arms use. Print the listed quantity once; it already covers two arms.
- `follower/` holds the parallel gripper, the camera mount and the follower board case.
- `leader/` holds the handle, trigger, wrist roll and the leader board case.

All parts fit a 180 × 180 mm bed. The largest part, the base, is 160 × 112.5 mm.

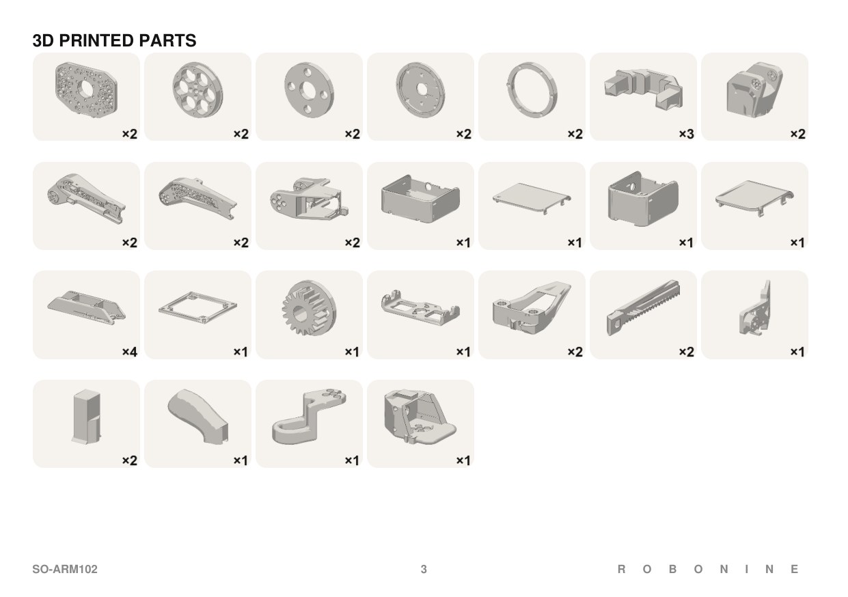
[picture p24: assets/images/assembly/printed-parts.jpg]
All printed parts of the kit


## Material

| Where | Material | Why |
|---|---|---|
| Arm links, base, servo holders | PET-CF, annealed if possible | Stiffest and most heat-resistant option tested near warm servos |
| Gripper clamps, covers, leader handle and trigger | PETG or PET-CF | Tougher against knocks |

The prototype was printed in **Fiberon PET-CF17**. In our filament tests, annealing cut PET-CF17
deflection after one hour at 65–70 °C from 3.4 mm to 0.3 mm. Annealing also makes the part more brittle,
so do not anneal parts that take impacts. Details:
[Choosing a filament for robotic arms](https://robonine.com/choosing-filament-for-robotic-arm-applications/).

The leader arm carries no load, so PLA should be enough for it. This has not been tested yet.

## 3MF slicer projects

The [3MF projects](../models/README.md#3mf-slicer-projects) include saved part orientations,
plate layouts and support settings. Open them as projects in **Bambu Studio**, select your
printer and filament, then slice and review the support preview.

| Project | Saved filament profile | Layer height | Walls | Top / bottom layers | Infill |
|---|---|---|:-:|:-:|---|
| [Leader](../models/3mf/SO102_leader.3mf) | Bambu PETG-CF | 0.20 mm | 3 | 5 / 4 | 15 % gyroid |
| [Follower arm](../models/3mf/SO102_follower.3mf) | Fiberon PET-CF17 | 0.20 mm | 6 | 6 / 6 | 30 % cubic |
| [Follower gripper and board case](../models/3mf/SO102_follower_gripper_box.3mf) | Bambu PETG-CF | 0.20 mm | 6 | 6 / 6 | 30 % cubic |

All three save a **Bambu Lab A1, 0.4 mm nozzle** profile on a **256 × 256 mm** bed.
Individual parts still fit a 180 × 180 mm bed, but the supplied layouts need to be split
across more plates for that size. Automatic tree supports are the global default;
some parts have support overrides, manual support settings or support blockers.

Print each project once for one complete kit, then print **one extra cable snap**:
the projects contain two in total, while the part list calls for three.

| Leader layout | Follower gripper and board case layout |
|:-:|:-:|
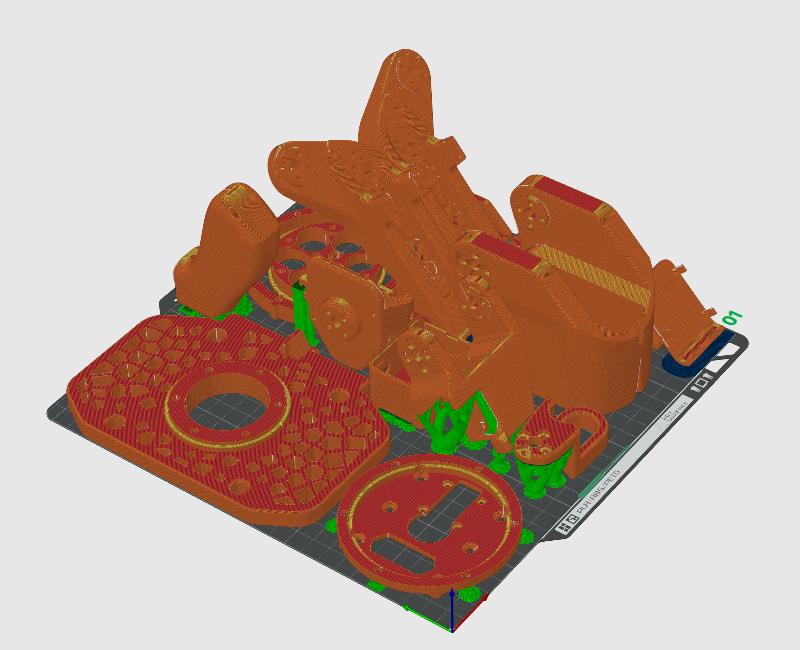
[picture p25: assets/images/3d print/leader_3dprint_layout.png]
Leader slicer layout
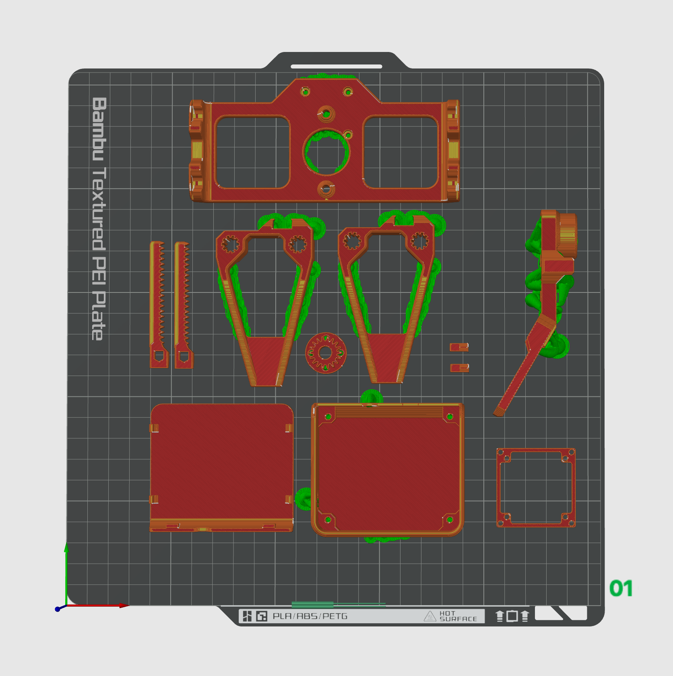
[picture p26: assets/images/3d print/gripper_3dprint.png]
Follower gripper and board case slicer layout
|  |  |

## Test-arm slicer settings

These are the settings the test arms were printed with. The supplied 3MF projects above
use different profiles; re-slice them to get filament and print-time estimates.

| Setting | Value |
|---|---|
| Walls | 4 |
| Top and bottom layers | 4 |
| Infill | 25 % gyroid |
| Supports | Yes, as needed |

For the gripper gear and gear racks use 100 % infill.

**More infill makes the follower stiffer.** With 100 % infill on all links and 35 % on the base,
the gripper deflection under 300 g dropped from 3.4 mm to 2.34 mm. The cost is filament and time:
about 720 g and 27 h instead of 500 g and 21 h, gripper not included.
For the leader, keep the infill low. It only has to be light and quick to print.

**Orientation matters.** Upper arms print best tilted, so the surface
comes out clean and the thin section does not crack. Lay long parts so the layer lines run
along the length of the part.

## Part list

Quantities are for one complete kit: one follower and one leader.

### Common parts, both arms

| Part number | Name | Qty |
|---|---|:-:|
| SO102.02.010 | Base | 2 |
| SO102.02.020 | Base ring | 2 |
| SO102.02.030 | Base washer | 2 |
| SO102.02.040 | Bottom top plate | 2 |
| SO102.02.050 | Bottom ring | 2 |
| SO102.02.060 | Bottom servo holder | 2 |
| SO102.02.070 | Bottom arm | 4 |
| SO102.02.080 | Upper arm left | 2 |
| SO102.02.080-01 | Upper arm right | 2 |
| SO102.02.090 | Wrist holder | 2 |
| SO102.02.130 | Cable snap | 3 |

### Follower only

| Part number | Name | Qty |
|---|---|:-:|
| RB9.01.062.011 | Main frame (D6.1) | 1 |
| RB9.01.062.024 | Clamp (D6.1) | 2 |
| RB9.01.062.030 | Gear rack | 2 |
| RB9.01.062.040 | Gear for gripper | 1 |
| RB9.01.062.100 | Nail | 2 |
| RB9.01.062.075 | Camera holder | 1 |
| RB9.01.062.090 | Camera spacer | 1 |
| SO102.02.100 | Board holder follower | 1 |
| SO102.02.100-01 | Board cap follower | 1 |

`(D6.1)` means the rod bores are sized for 6.1 mm. See the known issues in the main README if the gripper runs tight.

### Leader only

| Part number | Name | Qty |
|---|---|:-:|
| — | SO102 Handle | 1 |
| — | SO102 Trigger | 1 |
| — | SO102 Wrist roll | 1 |
| SO102.02.110 | Board holder leader | 1 |
| SO102.02.110-01 | Board cap leader | 1 |

## About the STL files

The STL files were exported from the STEP sources with a chord tolerance of 0.02 mm.
If you change a part, edit the STEP and export a new STL with the same name.

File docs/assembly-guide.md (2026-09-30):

# Assembly guide

This guide follows the printed booklet
[SO-ARM102_assembly_A5_v0.6.pdf](SO-ARM102_assembly_A5_v0.6.pdf) page by page.
Print the booklet on A5 landscape if you prefer paper.

Before you start:

- Print all parts from [printing.md](printing.md) and collect the hardware from [bom.md](bom.md).
- You need hex keys 1.5 mm (M2) and 2 mm (M3).
- Read two steps ahead before tightening anything. Two places in the current order are awkward, see [Known issues](../README.md#-known-issues).

> ⚠️ **The leader runs on 5 V, the follower on 12 V.** Keep the power supplies apart.

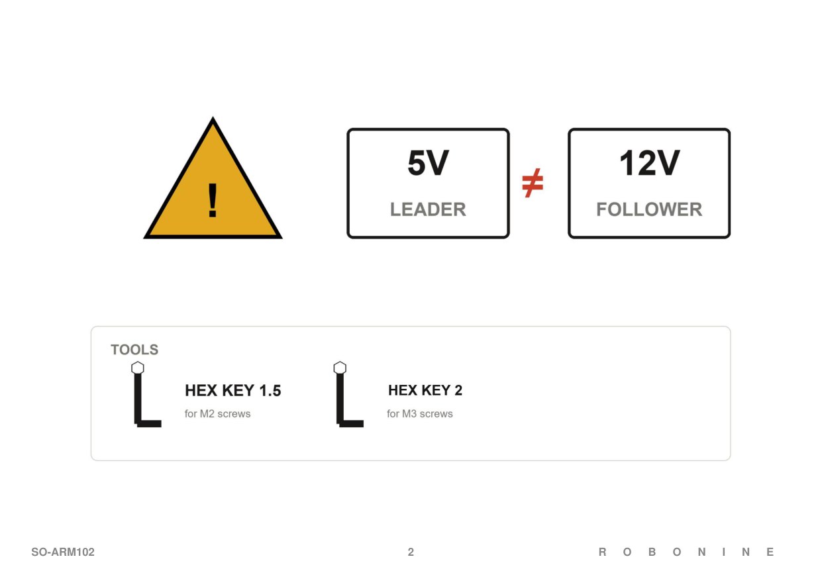
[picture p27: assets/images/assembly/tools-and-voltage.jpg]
Tools and voltage warning


## Order of work

1. Mount the horns on the servos.
2. Build the arm body **twice**, once for the follower and once for the leader (steps 1–11).
3. Build the parallel gripper (gripper steps 1–6).
4. Finish the follower: gripper, camera, controller (follower steps 1–5).
5. Finish the leader: handle, trigger, controller (leader steps 1–4).

## Servo IDs

Set each servo ID before it goes into the arm. Tools for setting IDs and calibrating are at
[lab.robonine.com](https://lab.robonine.com).

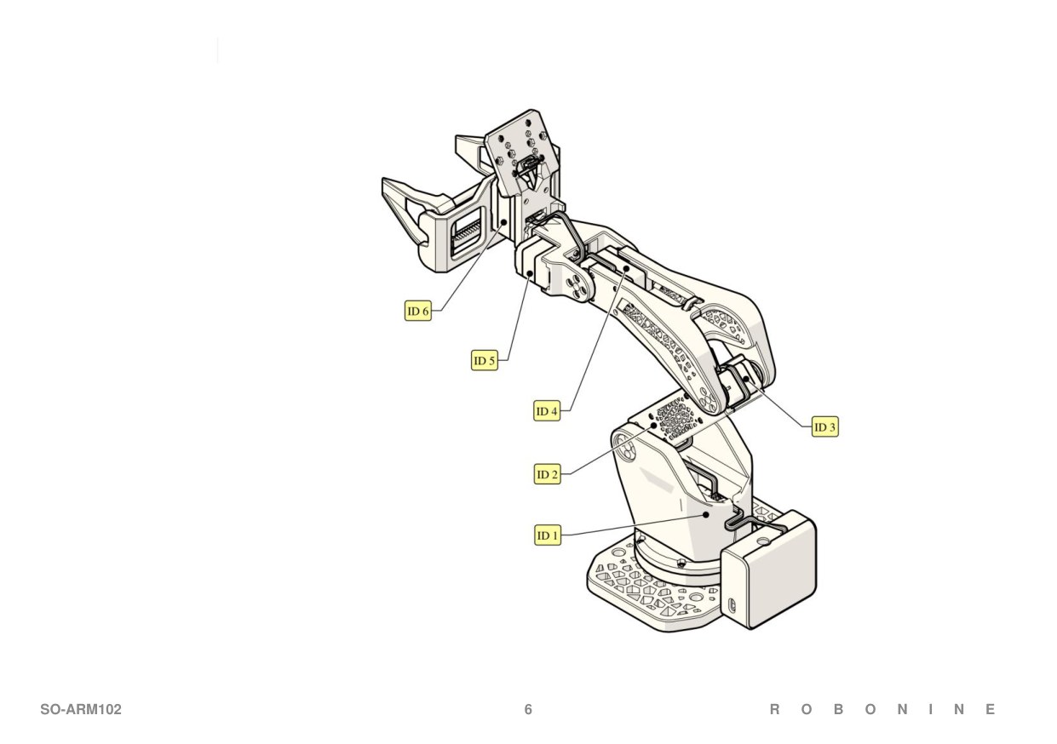
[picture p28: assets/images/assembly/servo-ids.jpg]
Servo IDs


| ID | Joint | Follower servo | Leader servo |
|:-:|---|---|---|
| 1 | Base rotation | STS3235 | STS3215 |
| 2 | Shoulder lift | STS3250 | STS3215 |
| 3 | Elbow flex | STS3250 | STS3215 |
| 4 | Wrist flex | STS3235 | STS3215 |
| 5 | Wrist roll | STS3215 | STS3215 |
| 6 | Gripper / trigger | STS3215 | STS3215 |

## 0. Servo horns

Mount one horn with an M3 × 6 screw on servo ID 1.
Servos ID 2, 3 and 4 get a horn on both sides. Horn screws come with the servos.

If you add O-rings to the leader, put them between the servo and the horn now. Getting this order wrong can jam the ring between the servo shell and the horn.

## 1–11. Arm body, follower and leader

Repeat these steps for both arms.

| Step | Parts | Fasteners |
|:-:|---|---|
| 1 | SO102.02.060 Bottom servo holder, SO102.02.040 Bottom top plate | 3 × M3×16, 3 × M3 nut |
| 2 | — | 3 × M3×16, 3 × M3 nut |
| 3 | Servo ID 1 | 4 × M2×6 |
| 4 | SO102.02.020 Base ring, bearing 6812, SO102.02.050 Bottom ring, SO102.02.010 Base | 6 × M3×16, 6 × M3 nut |
| 5 | SO102.02.030 Base washer | 4 × M3×10, 6 × M3×16 |
| 6 | Servos ID 2 and ID 3, 2 × SO102.02.070 Bottom arm, 2 short cables, 1 long cable | 16 × M2×6 |
| 7 | Servo ID 4, SO102.02.080-01 Upper arm right, 1 short cable | 4 × M2×6 |
| 8 | SO102.02.080 Upper arm left, 2 × SO102.02.130 Cable snap | 4 × M2×6, 8 × M3×10 |
| 9 | Servo ID 5, SO102.02.090 Wrist holder, servo horn | 1 × M3×6, 4 × 2×6 self-tapping |
| 10 | 1 short cable | 8 × M3×10 |
| 11 | — | 8 × M3×10 |

| | | |
|:-:|:-:|:-:|
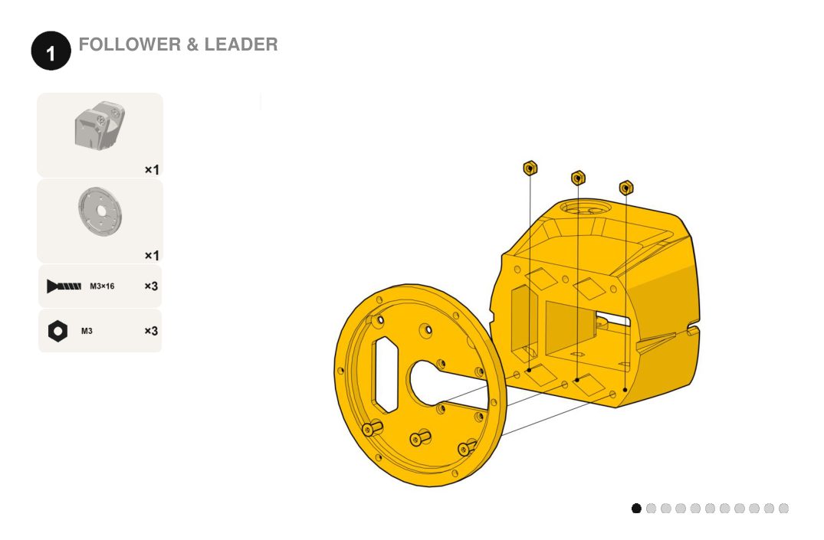
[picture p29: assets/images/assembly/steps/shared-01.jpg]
Step 1
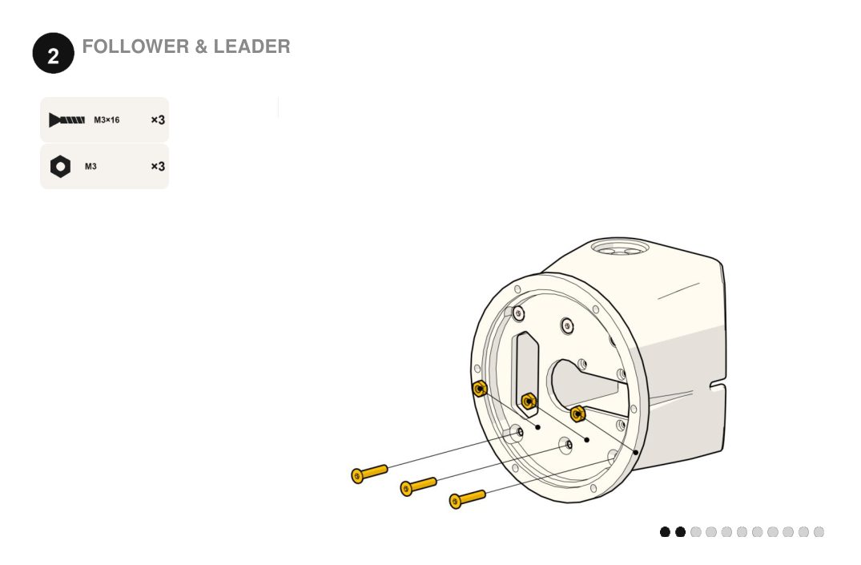
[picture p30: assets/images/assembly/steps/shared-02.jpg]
Step 2
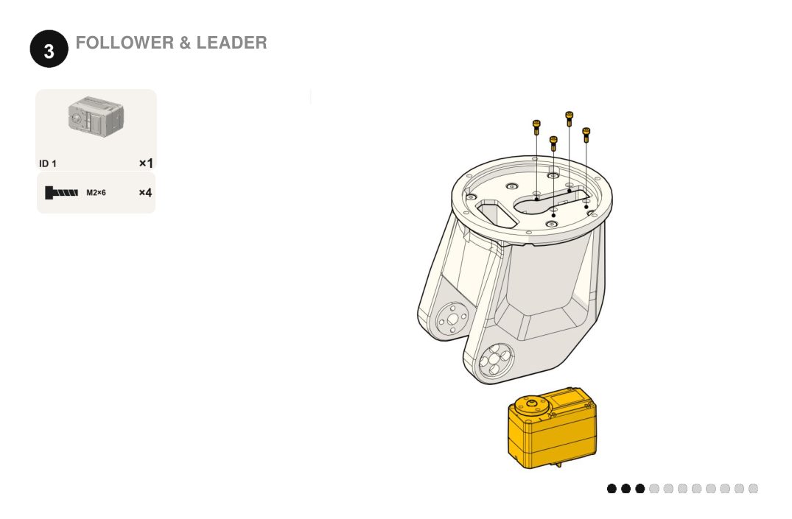
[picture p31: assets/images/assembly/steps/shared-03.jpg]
Step 3
|  |  |  |
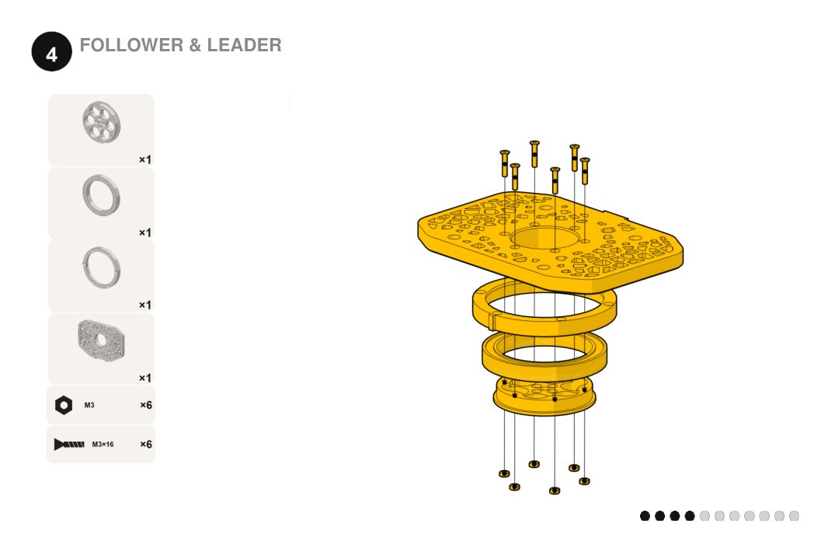
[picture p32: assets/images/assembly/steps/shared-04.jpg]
Step 4
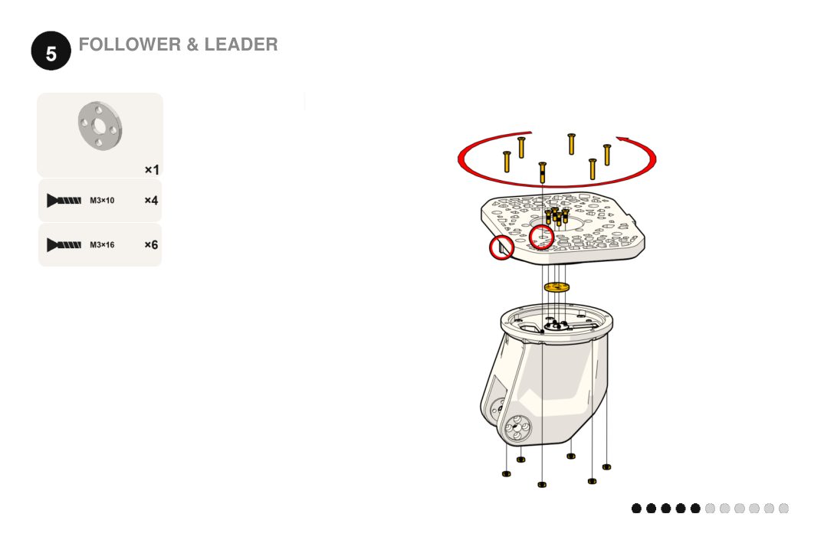
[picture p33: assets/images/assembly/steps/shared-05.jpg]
Step 5
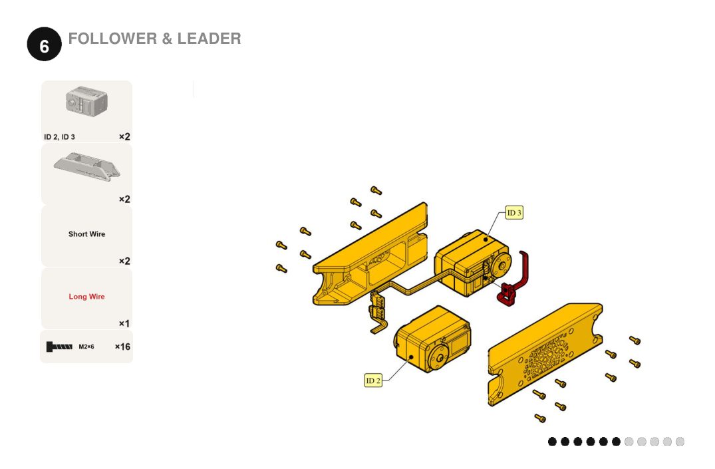
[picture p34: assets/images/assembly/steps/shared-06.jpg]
Step 6
|  |  |  |
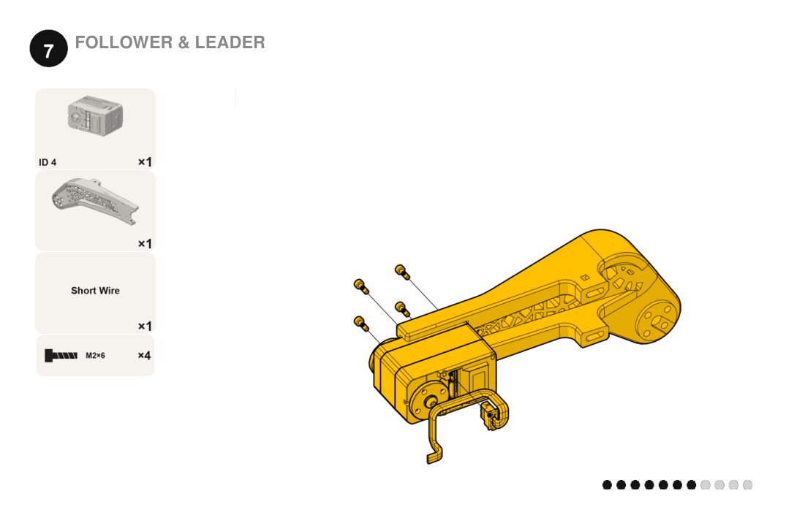
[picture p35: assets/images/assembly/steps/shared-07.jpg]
Step 7
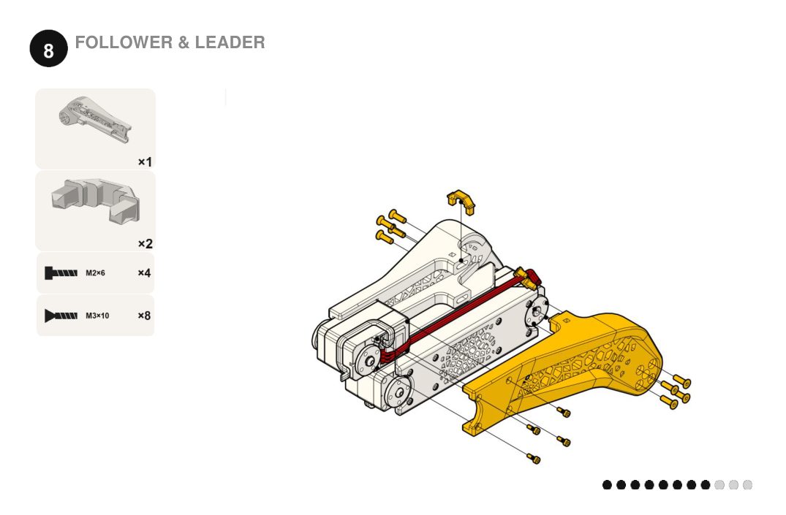
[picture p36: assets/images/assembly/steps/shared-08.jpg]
Step 8
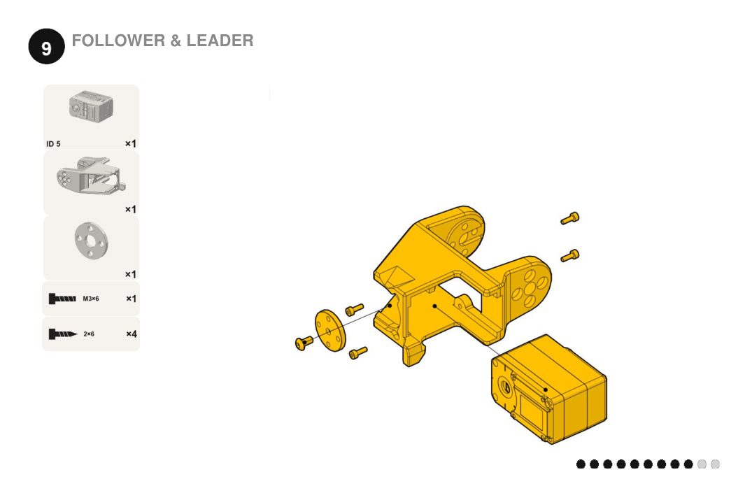
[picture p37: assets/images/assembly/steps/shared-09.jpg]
Step 9
|  |  |  |
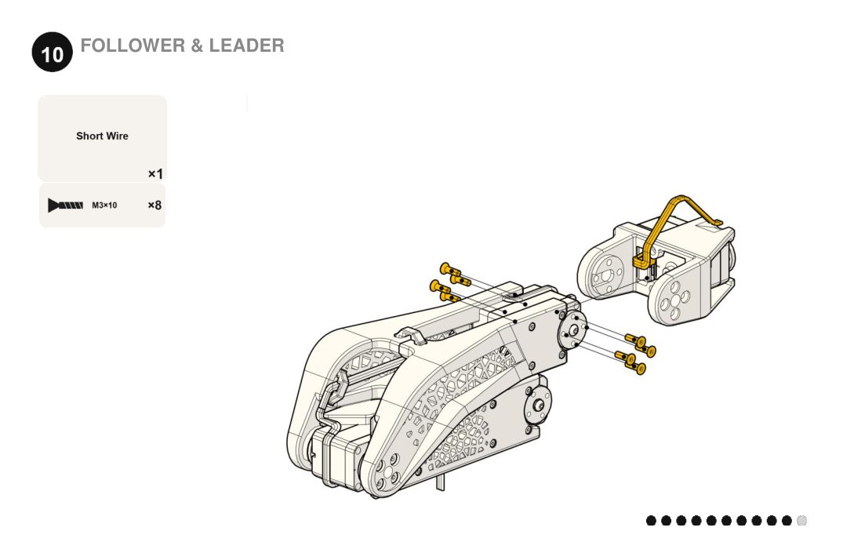
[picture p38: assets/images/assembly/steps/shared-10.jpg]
Step 10
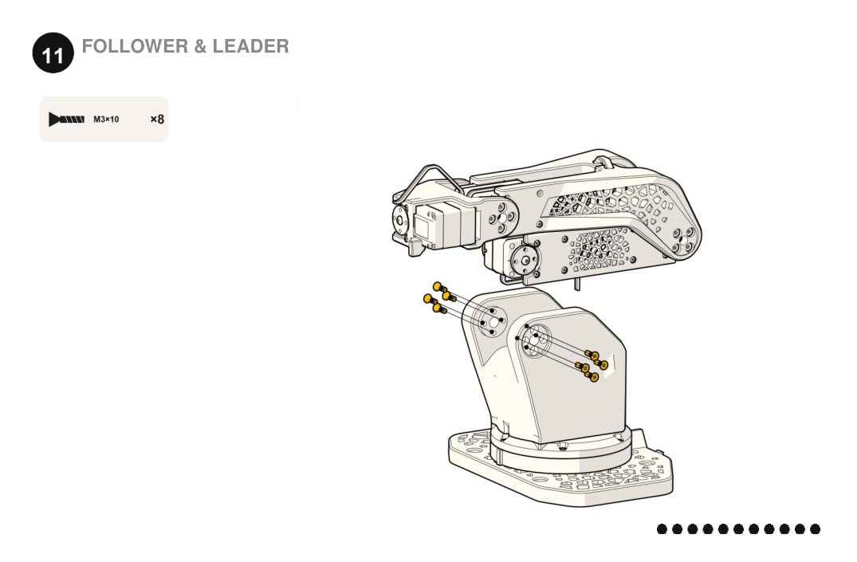
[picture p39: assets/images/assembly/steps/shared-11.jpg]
Step 11
|  |  | |

Check that each servo cable reaches the next joint with some slack before you close the joint.

## Gripper 1–6, follower only

| Step | Parts | Fasteners |
|:-:|---|---|
| 1 | RB9.01.062.040 Gear for gripper on the servo horn, servo ID 6 | 4 × M3×4 set screw, 1 × M3×6 |
| 2 | 2 × RB9.01.062.024 Clamp, 2 × RB9.01.062.030 Gear rack, 2 × RB9.01.062.100 Nail | — |
| 3 | 2 × rod Ø6 × 125 mm | — |
| 4 | RB9.01.062.011 Main frame, 2 × bearing MF106ZZ | 2 × M4×8 |
| 5 | Snap the rods into the main frame | — |
| 6 | Push the clamps to their outer stops, insert the servo | 3 × 2×6 self-tapping |

Tighten the set screws from the horn side towards the gear, so no gap opens between them.
Before step 6, move servo ID 6 to its minimum position, so the gripper closes fully and opens to the full 85 mm.
Slide both clamps along the rods by hand before closing up. They should move freely without binding.

| | | |
|:-:|:-:|:-:|
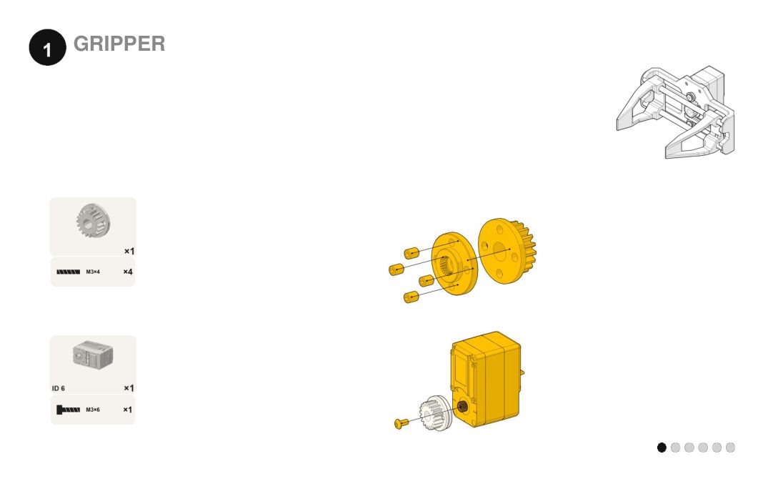
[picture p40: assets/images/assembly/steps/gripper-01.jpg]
Gripper 1
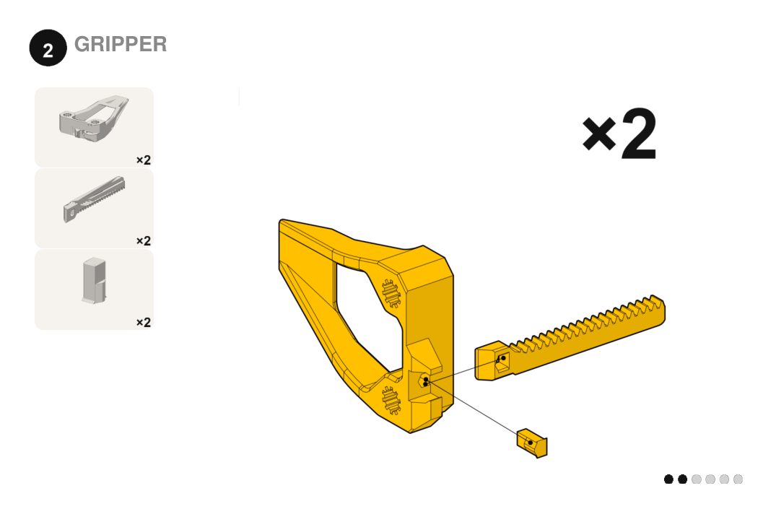
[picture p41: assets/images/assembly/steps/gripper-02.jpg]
Gripper 2
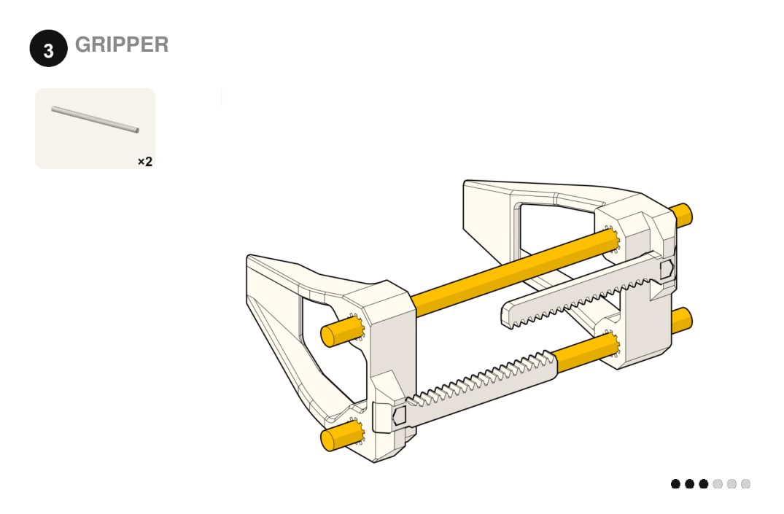
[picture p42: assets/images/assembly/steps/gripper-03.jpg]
Gripper 3
|  |  |  |
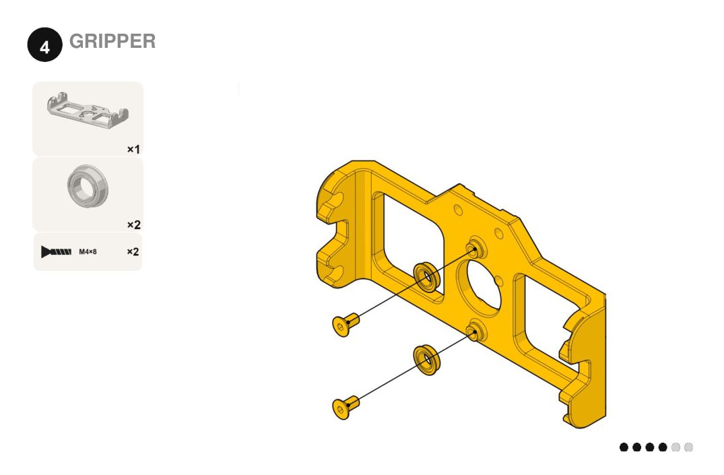
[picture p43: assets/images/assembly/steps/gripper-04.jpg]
Gripper 4
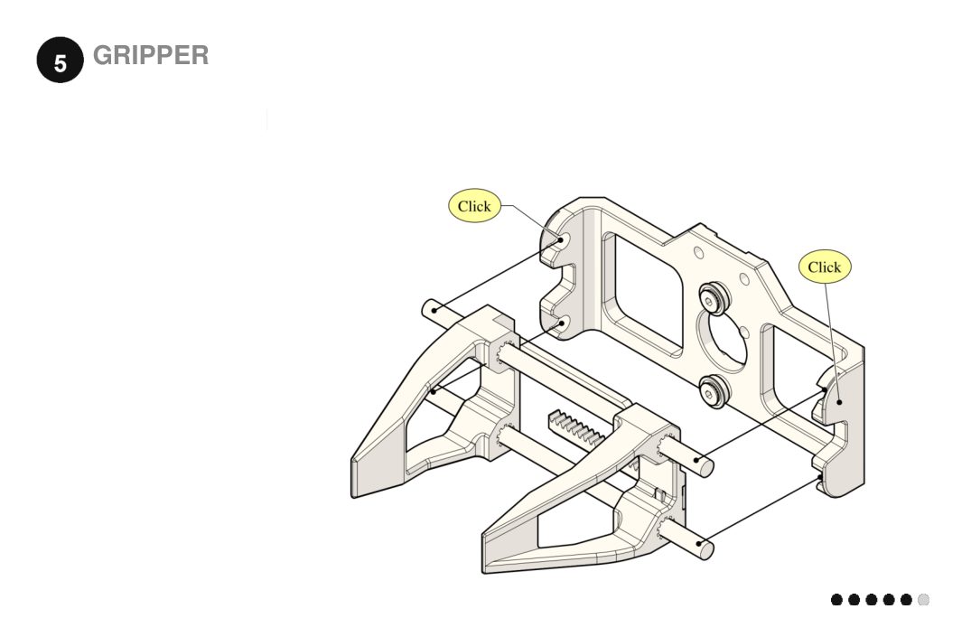
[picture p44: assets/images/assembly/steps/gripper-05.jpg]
Gripper 5
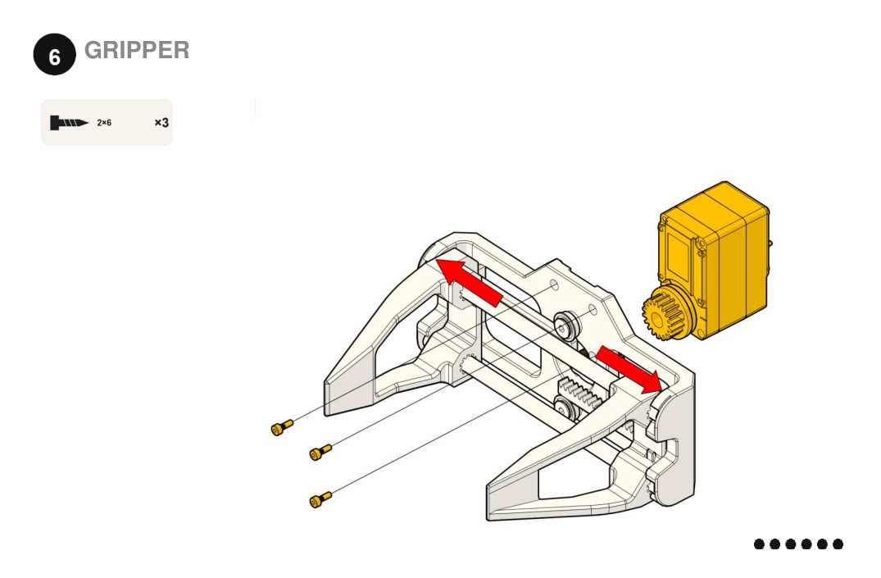
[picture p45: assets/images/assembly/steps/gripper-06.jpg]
Gripper 6
|  |  |  |

## Follower 1–5

| Step | Parts | Fasteners |
|:-:|---|---|
| 1 | RB9.01.060.075 Camera holder | 4 × M3×10 |
| 2 | Gripper assembly onto the wrist | 4 × 2×6 self-tapping |
| 3 | RB9.01.062.090 Camera spacer, USB camera | 4 × M2×8, 4 × M2 nut |
| 4 | SO102.02.100 Board holder follower, Waveshare Bus Servo Driver HAT | 4 × M2×8, 4 × M2 nut |
| 5 | SO102.02.100-01 Board cap follower, long cable | — |

| | | |
|:-:|:-:|:-:|
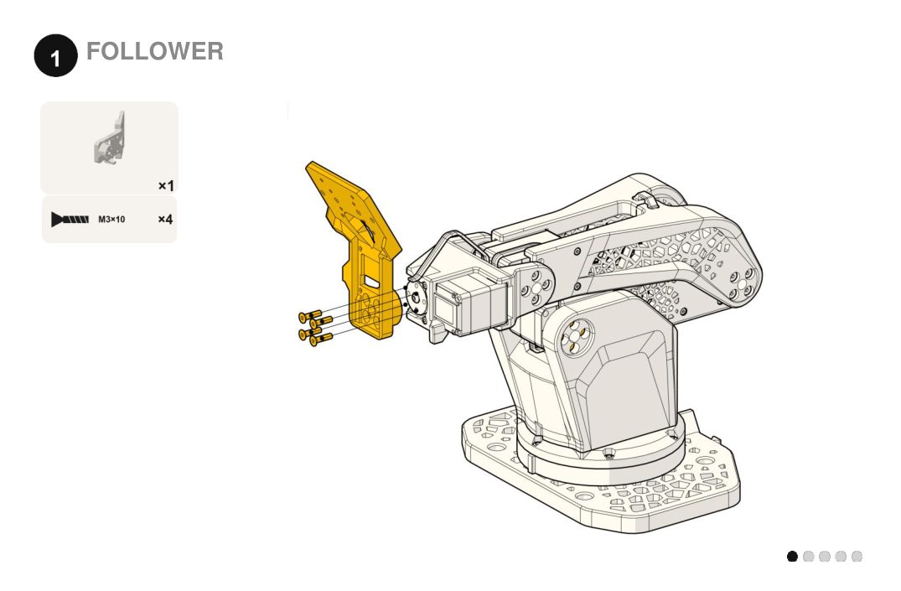
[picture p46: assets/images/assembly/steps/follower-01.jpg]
Follower 1
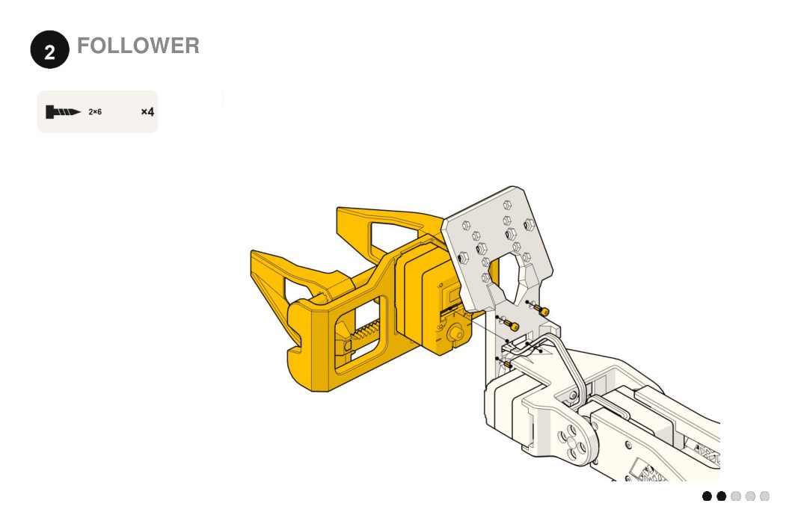
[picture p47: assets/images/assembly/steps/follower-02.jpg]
Follower 2
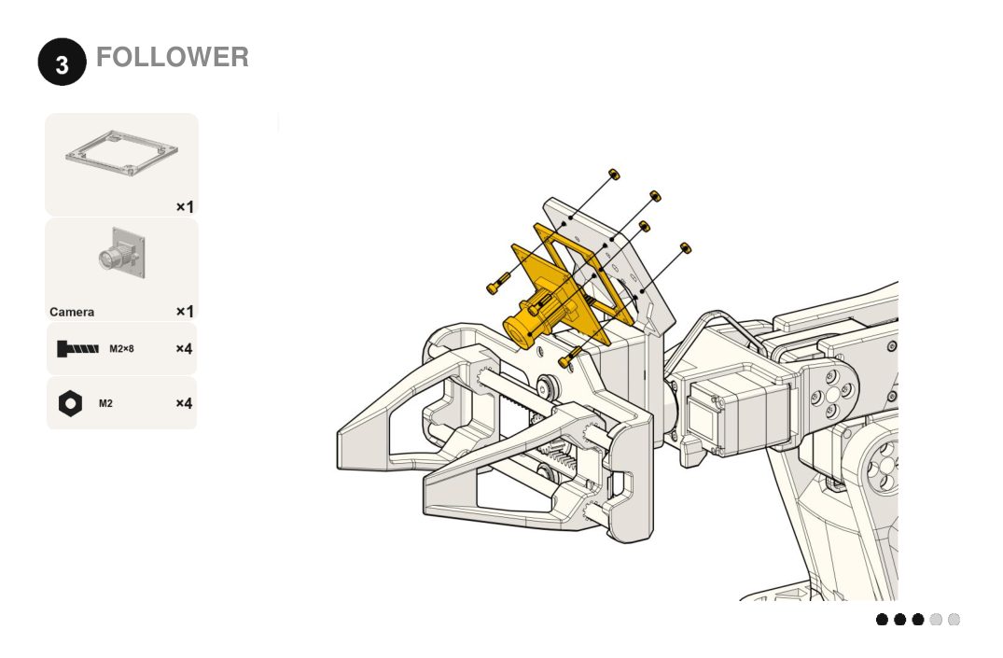
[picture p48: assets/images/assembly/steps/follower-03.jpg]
Follower 3
|  |  |  |
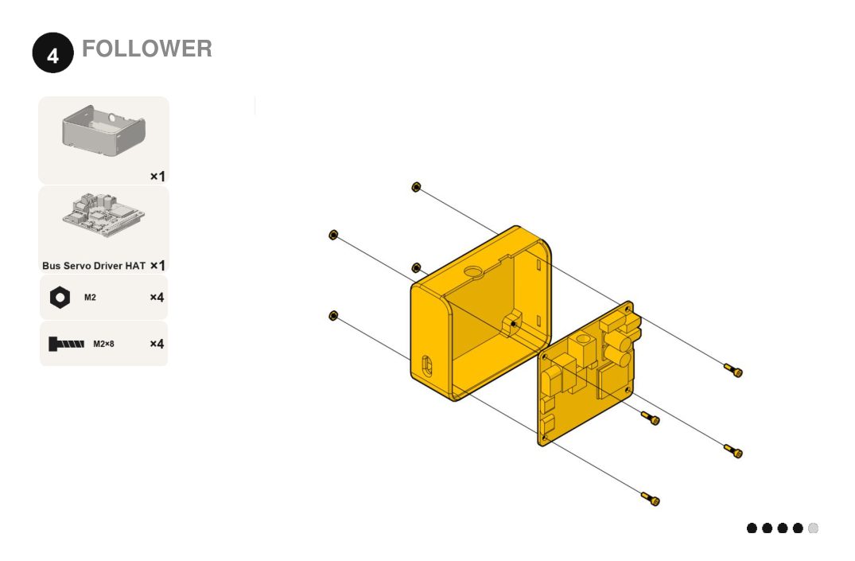
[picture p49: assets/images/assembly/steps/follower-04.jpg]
Follower 4
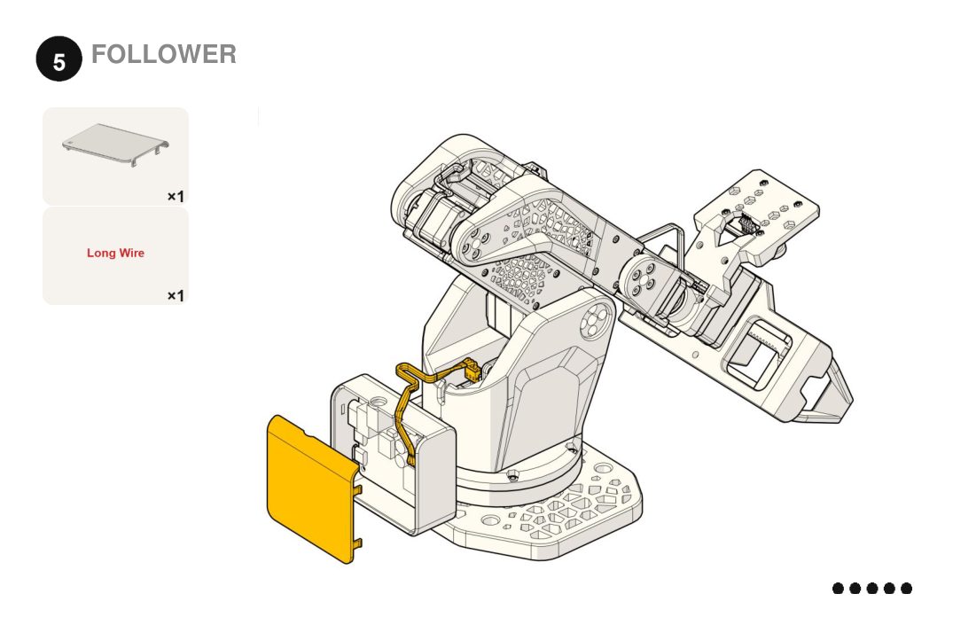
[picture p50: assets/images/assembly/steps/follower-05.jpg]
Follower 5
|  |  | |

## Leader 1–4

| Step | Parts | Fasteners |
|:-:|---|---|
| 1 | SO102 Handle, SO102 Wrist roll | 4 × M3×6, 1 × 2×6 self-tapping |
| 2 | SO102 Trigger, servo ID 6 | 4 × M3×6, 4 × 2×6 self-tapping |
| 3 | SO102.02.110 Board holder leader, Waveshare Bus Servo Adapter | 4 × M2×8, 4 × M2 nut |
| 4 | SO102.02.110-01 Board cap leader, long cable | — |

| | |
|:-:|:-:|
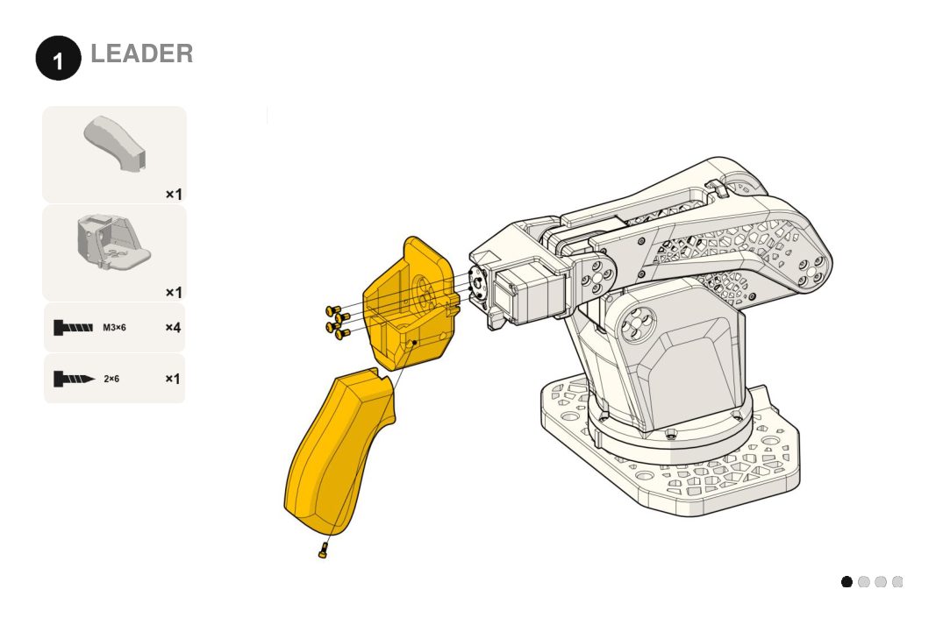
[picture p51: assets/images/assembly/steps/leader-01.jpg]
Leader 1
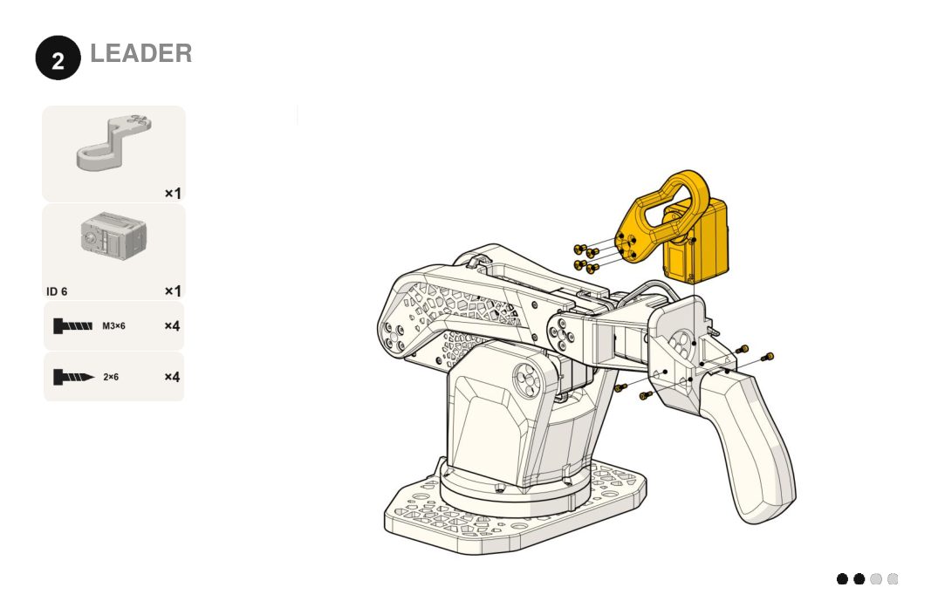
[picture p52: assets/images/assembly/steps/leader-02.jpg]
Leader 2
|  |  |
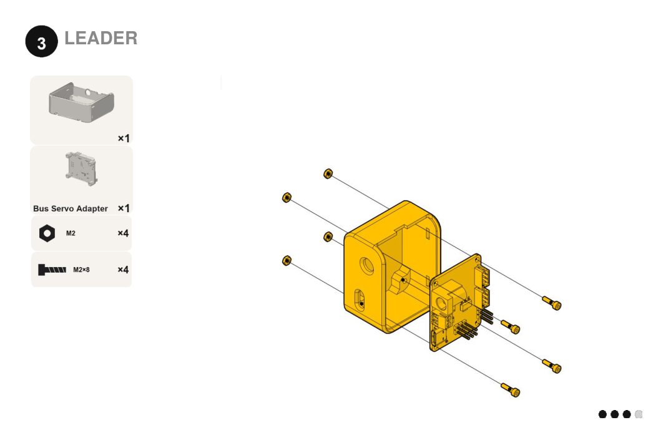
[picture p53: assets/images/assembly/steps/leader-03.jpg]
Leader 3
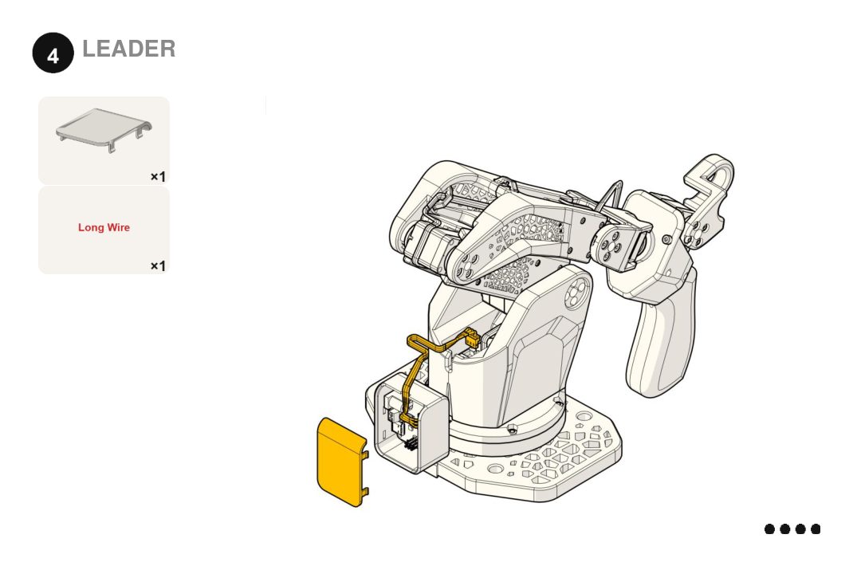
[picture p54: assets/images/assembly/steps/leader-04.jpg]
Leader 4
|  |  |

## Mounting and first start

1. Clamp each base to the table with two C-clamps.
2. Connect the follower controller to the 12 V supply and the leader controller to the 5 V supply.
3. Connect both controllers to the computer with USB-C.
4. Calibrate both arms and start teleoperation at [lab.robonine.com](https://lab.robonine.com), or with the LeRobot SO-101 workflow.

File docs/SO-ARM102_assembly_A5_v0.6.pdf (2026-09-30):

# SO-ARM102

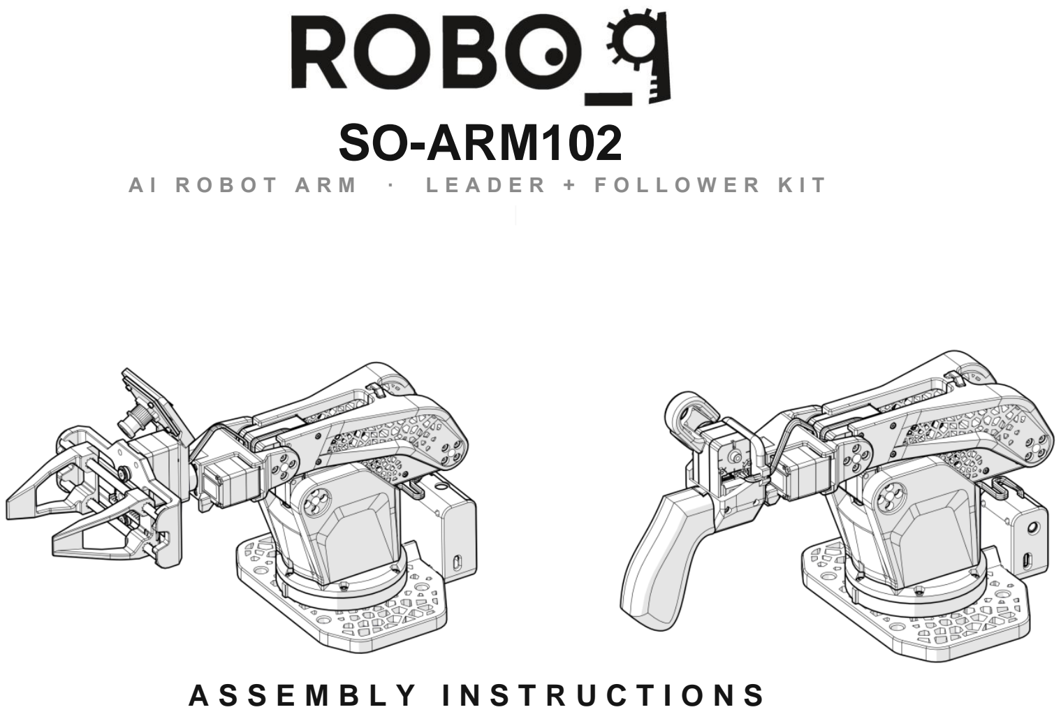
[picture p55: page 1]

A I R O B O T A R M | · | L E A D E R + F O L L O W E R K I T

## A S S E M B L Y I N S T R U C T I O N S

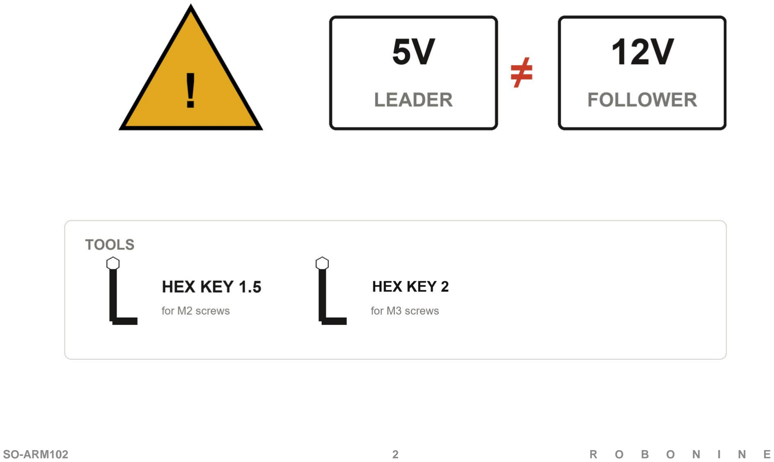
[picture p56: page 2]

SO-ARM102 | 2 | R | O | B | O | N | I | N | E

## 3D PRINTED PARTS

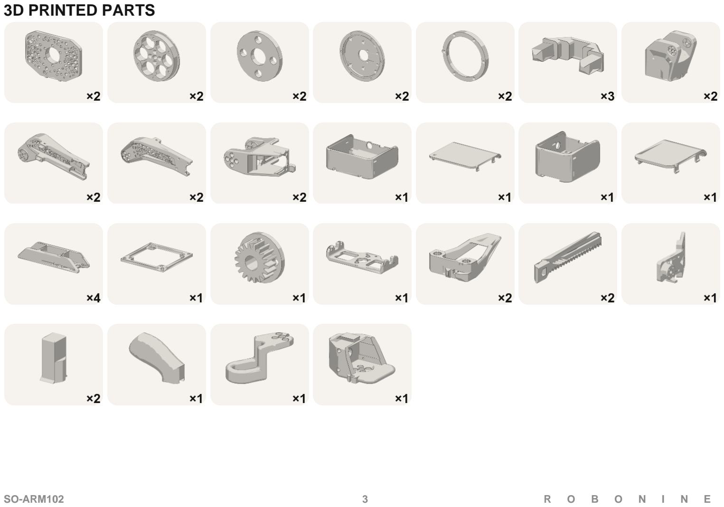
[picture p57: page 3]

SO-ARM102 | 3 | R | O | B | O | N | I | N | E

SO-ARM102 | 4 | R | O | B | O | N | I | N | E

## HARDWARE

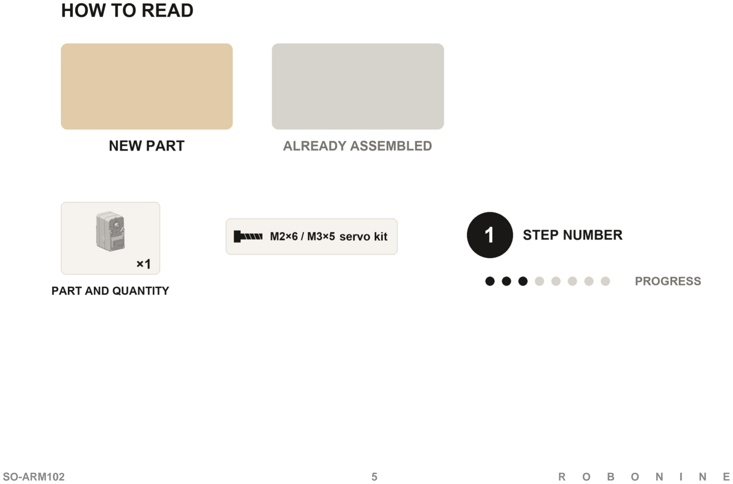
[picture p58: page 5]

SO-ARM102 | 5 | R | O | B | O | N | I | N | E

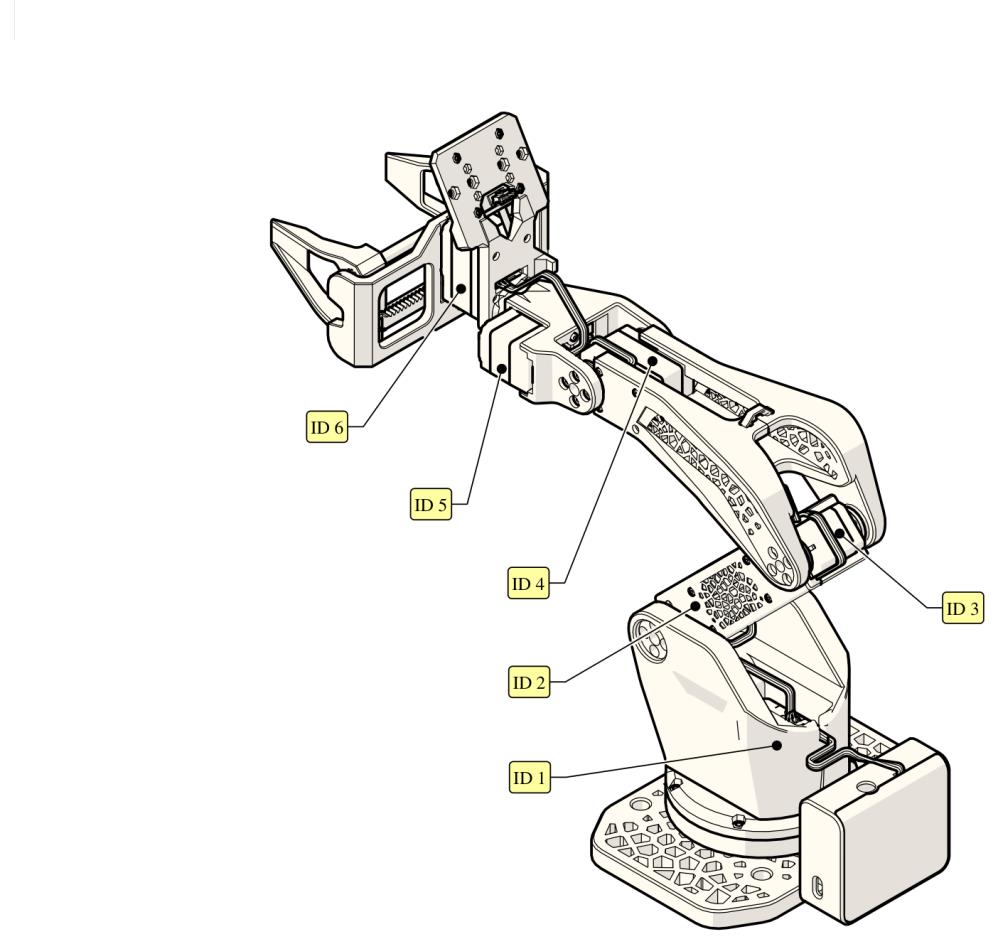
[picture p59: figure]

SO-ARM102 | 6 | R | O | B | O | N | I | N | E

# SERVO ID 1

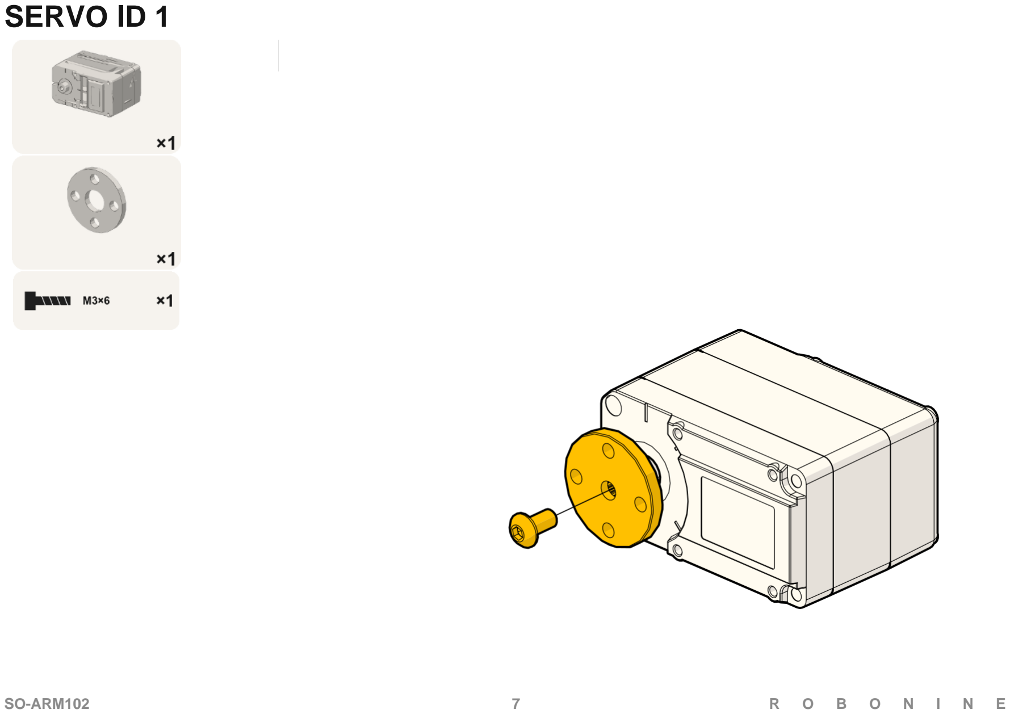
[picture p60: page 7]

SO-ARM102 | 7 | R | O | B | O | N | I | N | E

# SERVOS ID 2, ID 3, ID 4

SO-ARM102 | 8 | R | O | B | O | N | I | N | E

## FOLLOWER & LEADER

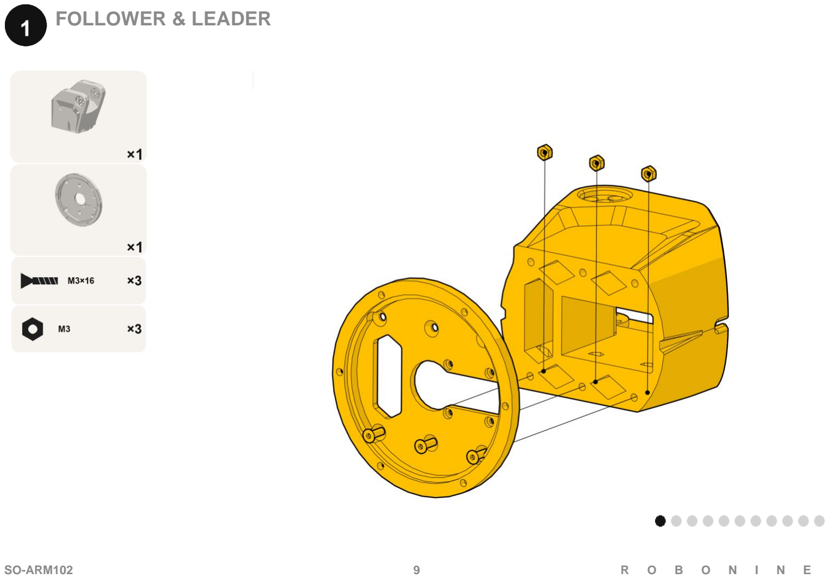
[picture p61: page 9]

SO-ARM102 | 9 | R | O | B | O | N | I | N | E

## FOLLOWER & LEADER

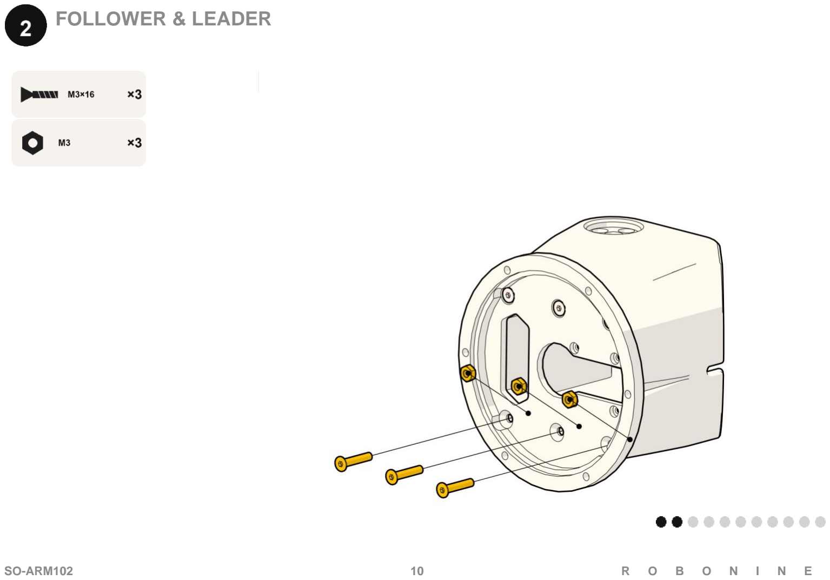
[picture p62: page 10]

SO-ARM102 | 10 | R | O | B | O | N | I | N | E

## FOLLOWER & LEADER

SO-ARM102 | 11 | R | O | B | O | N | I | N | E

## FOLLOWER & LEADER

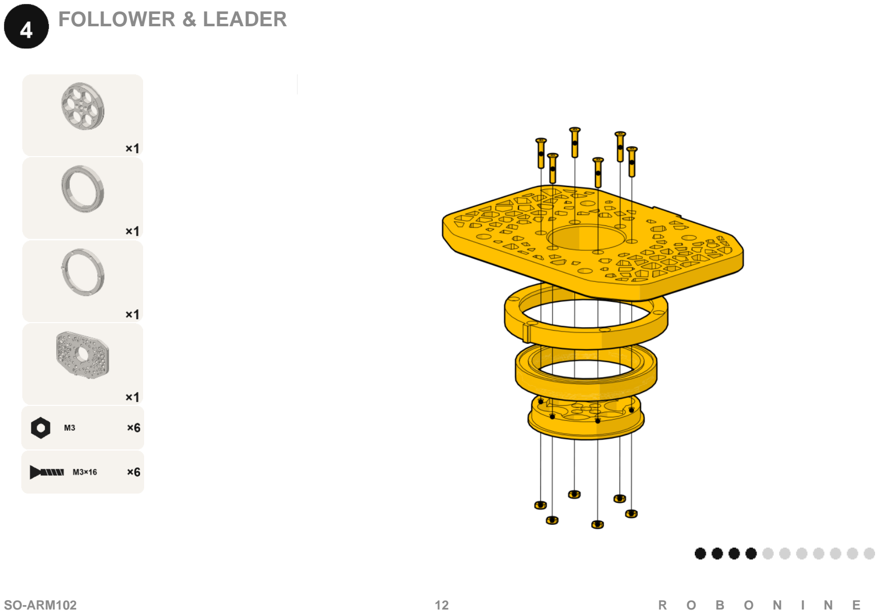
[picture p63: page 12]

SO-ARM102 | 12 | R | O | B | O | N | I | N | E

## FOLLOWER & LEADER


SO-ARM102 | 13 | R | O | B | O | N | I | N | E

## FOLLOWER & LEADER

SO-ARM102 | 14 | R | O | B | O | N | I | N | E

## FOLLOWER & LEADER


SO-ARM102 | 15 | R | O | B | O | N | I | N | E

## FOLLOWER & LEADER


SO-ARM102 | 16 | R | O | B | O | N | I | N | E

## FOLLOWER & LEADER

SO-ARM102 | 17 | R | O | B | O | N | I | N | E

## FOLLOWER & LEADER


SO-ARM102 | 18 | R | O | B | O | N | I | N | E

SO-ARM102 | 19 | R | O | B | O | N | I | N | E

## FOLLOWER & LEADER


SO-ARM102 | 20 | R | O | B | O | N | I | N | E

# GRIPPER

# GRIPPER


SO-ARM102 | 21 | R | O | B | O | N | I | N | E

# GRIPPER

SO-ARM102 | 22 | R | O | B | O | N | I | N | E

# GRIPPER


SO-ARM102 | 23 | R | O | B | O | N | I | N | E


SO-ARM102 | 24 | R | O | B | O | N | I | N | E

# GRIPPER

SO-ARM102 | 25 | R | O | B | O | N | I | N | E

# GRIPPER

# FOLLOWER


SO-ARM102 | 26 | R | O | B | O | N | I | N | E


SO-ARM102 | 27 | R | O | B | O | N | I | N | E

# FOLLOWER

# FOLLOWER

SO-ARM102 | 28 | R | O | B | O | N | I | N | E

# FOLLOWER


SO-ARM102 | 29 | R | O | B | O | N | I | N | E

# FOLLOWER


SO-ARM102 | 30 | R | O | B | O | N | I | N | E

# LEADER

SO-ARM102 | 31 | R | O | B | O | N | I | N | E

# LEADER


SO-ARM102 | 32 | R | O | B | O | N | I | N | E

# LEADER


SO-ARM102 | 33 | R | O | B | O | N | I | N | E

# LEADER

SO-ARM102 | 34 | R | O | B | O | N | I | N | E


SO-ARM102 | 35 | R | O | B | O | N | I | N | E

# SOFTWARE

# LAB.ROBONINE.COM

A S S E M B L Y | · | C A L I B R A T I O N | · | L E S S O N S

## robonine.com

## hello@robonine.com

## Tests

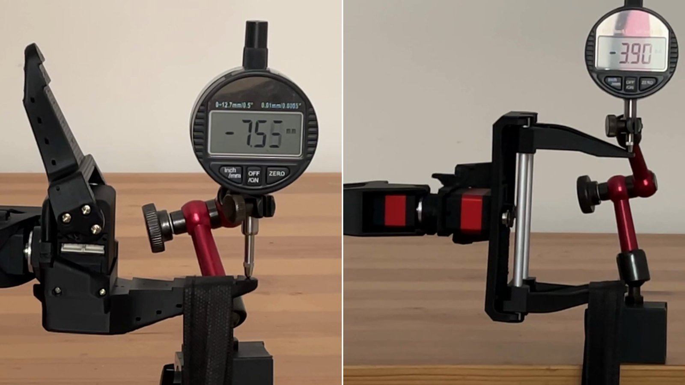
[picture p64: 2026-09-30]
assets/images/tests/stiffness-dial-comparison.jpg

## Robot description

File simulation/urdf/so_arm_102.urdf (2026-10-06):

<?xml version='1.0' encoding='utf-8'?>
<robot name="so_arm_102_pre_for_urdf_v5">
  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
  <link name="base_link">
    <inertial>
      <origin xyz="-0.00753657459228 2.70964811146e-05 0.013641047398" rpy="0 0 0" />
      <mass value="0.178499229726" />
      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
    </inertial>
    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
  </link>
  <link name="link1_1">
    <inertial>
      <origin xyz="0.000323477926688 -9.49285422888e-06 0.0277445919724" rpy="0 0 0" />
      <mass value="0.201603775922" />
      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
    </inertial>
    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
  </link>
  <link name="link2_1">
    <inertial>
      <origin xyz="-9.08588393138e-05 0.0179996080154 0.0565027997369" rpy="0 0 0" />
      <mass value="0.180993297738" />
      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
    </inertial>
    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
  </link>
  <link name="link3_1">
    <inertial>
      <origin xyz="0.0899345844067 -0.0180532098499 0.030929698344" rpy="0 0 0" />
      <mass value="0.121036400289" />
      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
    </inertial>
    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
  </link>
  <link name="link4_1">
    <inertial>
      <origin xyz="0.0367612549493 -0.00682773158541 -9.36509085222e-05" rpy="0 0 0" />
      <mass value="0.0850684506718" />
      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
    </inertial>
    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
  </link>
  <link name="link5_1">
    <inertial>
      <origin xyz="0.0344926242899 -3.24353462452e-05 0.0128432467385" rpy="0 0 0" />
      <mass value="0.106616468137" />
      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
    </inertial>
    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
  </link>
  <link name="clamp1_1">
    <inertial>
      <origin xyz="0.0150861322583 -0.0085189835284 -0.0166385856799" rpy="0 0 0" />
      <mass value="0.00734953722517" />
      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
    </inertial>
    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
  </link>
  <link name="clamp2_1">
    <inertial>
      <origin xyz="0.0150861312617 0.00851898352954 -0.0153534196604" rpy="0 0 0" />
      <mass value="0.00734953759363" />
      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
    </inertial>
    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
  </link>
  <joint name="base_to_link1" type="revolute">
    <origin xyz="-0.006 -1.10978314851e-16 0.025" rpy="0 0 0" />
    <parent link="base_link" />
    <child link="link1_1" />
    <axis xyz="-3.48927236311e-15 -1.38855301773e-17 -1" />
    <limit effort="100" velocity="100" lower="-3.07177948351" upper="3.07177948351" />
  </joint>
  <joint name="link1_to_link2" type="revolute">
    <origin xyz="0.04 -0.018 0.073356707952" rpy="0 0 0" />
    <parent link="link1_1" />
    <child link="link2_1" />
    <axis xyz="3.7576779295e-14 -1 3.11848821907e-14" />
    <limit effort="100" velocity="100" lower="-2.32128790515" upper="1.58824961931" />
  </joint>
  <joint name="link2_to_link3" type="revolute">
    <origin xyz="3.39589458789e-05 0.035999879491 0.113000833762" rpy="0 0 0" />
    <parent link="link2_1" />
    <child link="link3_1" />
    <axis xyz="5.4643524895e-08 -1 3.71447673953e-08" />
    <limit effort="100" velocity="100" lower="-1.57079632679" upper="2.67035375555" />
  </joint>
  <joint name="link3_to_link4" type="revolute">
    <origin xyz="0.135059233654 -2.61233757511e-07 0.0336375809223" rpy="0 0 0" />
    <parent link="link3_1" />
    <child link="link4_1" />
    <axis xyz="-5.21611917629e-08 1 -3.41984371354e-08" />
    <limit effort="100" velocity="100" lower="-1.72787595947" upper="1.69296937443" />
  </joint>
  <joint name="link4_to_link5" type="revolute">
    <origin xyz="0.0591945817497 -0.0180002669618 -4.03637807994e-05" rpy="0 0 0" />
    <parent link="link4_1" />
    <child link="link5_1" />
    <axis xyz="-1 -4.90398764451e-08 1.40482066922e-10" />
    <limit effort="100" velocity="100" lower="-2.87979326579" upper="2.84488668075" />
  </joint>
  <joint name="clamp1" type="prismatic">
    <origin xyz="0.0639999993385 0.0165020797222 0.0159979235363" rpy="0 0 0" />
    <parent link="link5_1" />
    <child link="clamp1_1" />
    <axis xyz="-5.21612507542e-08 1 4.50838078172e-08" />
    <limit effort="100" velocity="100" lower="0" upper="0.0415" />
  </joint>
  <joint name="clamp2" type="prismatic">
    <origin xyz="0.0640000007627 -0.0154979202778 0.0159979219163" rpy="0 0 0" />
    <parent link="link5_1" />
    <child link="clamp2_1" />
    <axis xyz="-4.9039873492e-08 1 4.73420869362e-08" />
    <limit effort="100" velocity="100" lower="-0.0415" upper="3.46944695195e-17" />
    <mimic joint="clamp1" multiplier="-1" offset="0" />
  </joint>
</robot>

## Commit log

2026-09-30 Publish SO-ARM 102 v0.1: models, print and assembly docs
    - models/: 24 STEP sources from the release folder plus 25 print-ready STLs
    (STLs exported from STEP; camera holder is STL only), split into
    common/, follower/ and leader/
    - docs/: printing settings and quantities, BOM with servo assignment per
    joint, step-by-step assembly guide with booklet drawings, specifications
    and measured results against SO-ARM 101, assembly booklet v0.6 PDF
    - Multi-licence setup as in the parallel gripper repo: CERN-OHL-P-2.0
    hardware, Apache-2.0 config, CC BY 4.0 docs, REUSE.toml, NOTICE
    - CI: pre-commit with reuse lint and a 5 MB file size limit
    - README lists known issues from the first external te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
    [RB9.01.060.075 Camera holder.stl, RB9.01.062.011 Main frame (D6.1).STEP, RB9.01.062.011 Main frame (D6.1).stl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]
2026-09-30 README: live photo, preview video, configurations, full team
    - Hero image is now a live photo that links to the preview video
    - Add the preview video (re-encoded to 2 MB) and an animated GIF preview
    - Show the single-arm (1 leader + 1 follower) and bimanual
    (2 leaders + 2 followers) setups in their own section
    - Credit the full team: design, industrial design, structural analysis,
    project management, testing
    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
2026-09-30 README: link to the SO-ARM 102 kit in the shop
    Claude-Session: https://claude.ai/code/session_01BvHSNdcAoYuH2WcActRRmD
2026-10-05 added camera holder step
    [RB9.01.062.075 Camera holder.STEP]
2026-10-05 updated camera holder stl
    [RB9.01.062.075 Camera holder.STL]
2026-10-05 deleted old camera holder stl
    [RB9.01.060.075 Camera holder.stl]
2026-10-05 updated base step
    [SO102.02.010 Base.STEP]
2026-10-05 fixed camera holder part number
2026-10-05 cables info update
2026-10-05 Update the base STL from the release export
    [SO102.02.010 Base.stl]
2026-10-06 Add 3mf files
    [SO102_follower.3mf, SO102_follower_gripper_box.3mf, SO102_leader.3mf]
2026-10-06 Add urdf
    [base_link.stl, clamp1_1.stl, clamp2_1.stl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]
2026-10-06 Fix final newlines in SO-102 robot descriptions
    [materials.xacro, so_arm_102.urdf, so_arm_102.xacro]
2026-10-07 docs(readme): clarify five arm DOF plus gripper (#5)
2026-10-09 Update bom.md (#7)
    * Update bom.md
    * servo price update
2026-10-09 docs: total BOM costs and add README summary (#8)
2026-10-22 docs: reconcile v0.2.0 release, BOM and translated guides (#22)
2026-10-22 Update the assembly guide to booklet v0.7.
    Shared steps now include the Bus Servo Adapter on both arms, and the gripper, follower, and leader lists use the current part names.
2026-10-26 docs: sync nine assembly translations with booklet v0.7 (#25)
2026-10-26 docs: add gripper rod-fit test plate
2026-10-26 docs: recommend plastic-compatible threadlocker
2026-10-26 docs: specify aluminium or carbon guide tubes
2026-10-27 docs: simplify README introductions across all languages (#31)
    * docs: clarify SO-ARM lineage in all README introductions
    * docs: simplify README introductions for readability
    * docs: remove unsupported dataset and policy compatibility claims
2026-10-28 docs: source aluminium guide alternative cut from one tube
2026-10-28 docs: use verified Amazon US and EU aluminium tube listings
2026-10-28 docs: show tube pack quantities without lengths in price cells
2026-10-30 Update printing.md to PLA+
2026-10-30 Update bom.md added o-rings, PLA+

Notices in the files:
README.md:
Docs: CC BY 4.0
